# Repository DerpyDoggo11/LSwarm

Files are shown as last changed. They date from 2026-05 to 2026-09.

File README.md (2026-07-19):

# LSwarm Mk.1
Micro-drone swarm as a light display

## 3D Preview
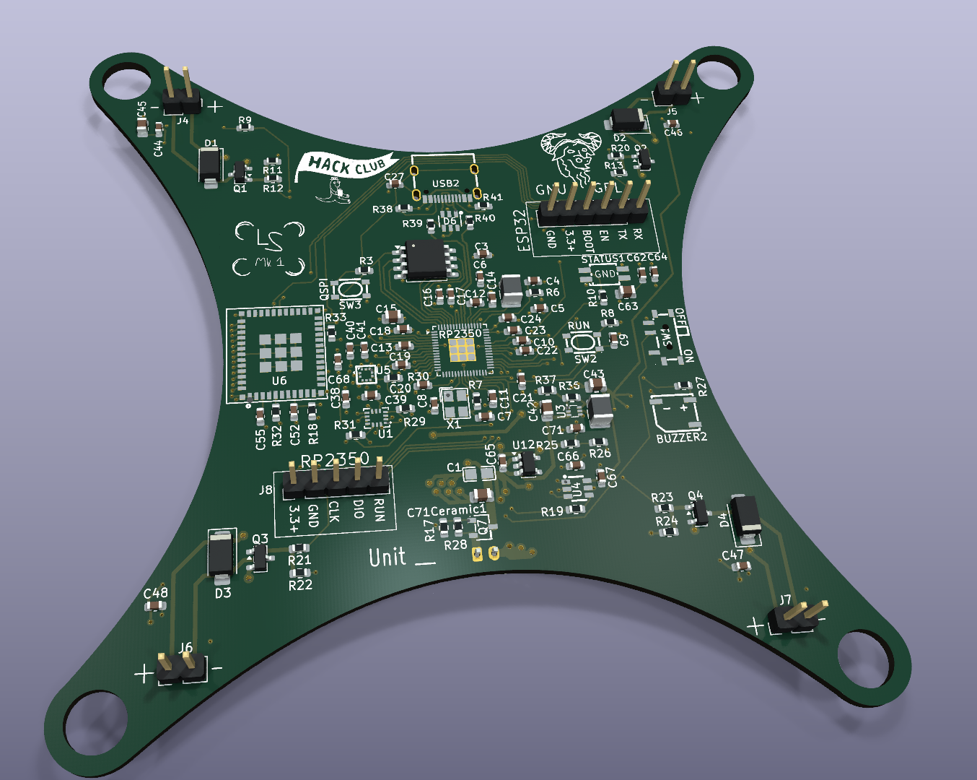
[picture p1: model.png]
3D PCB


## Wiring
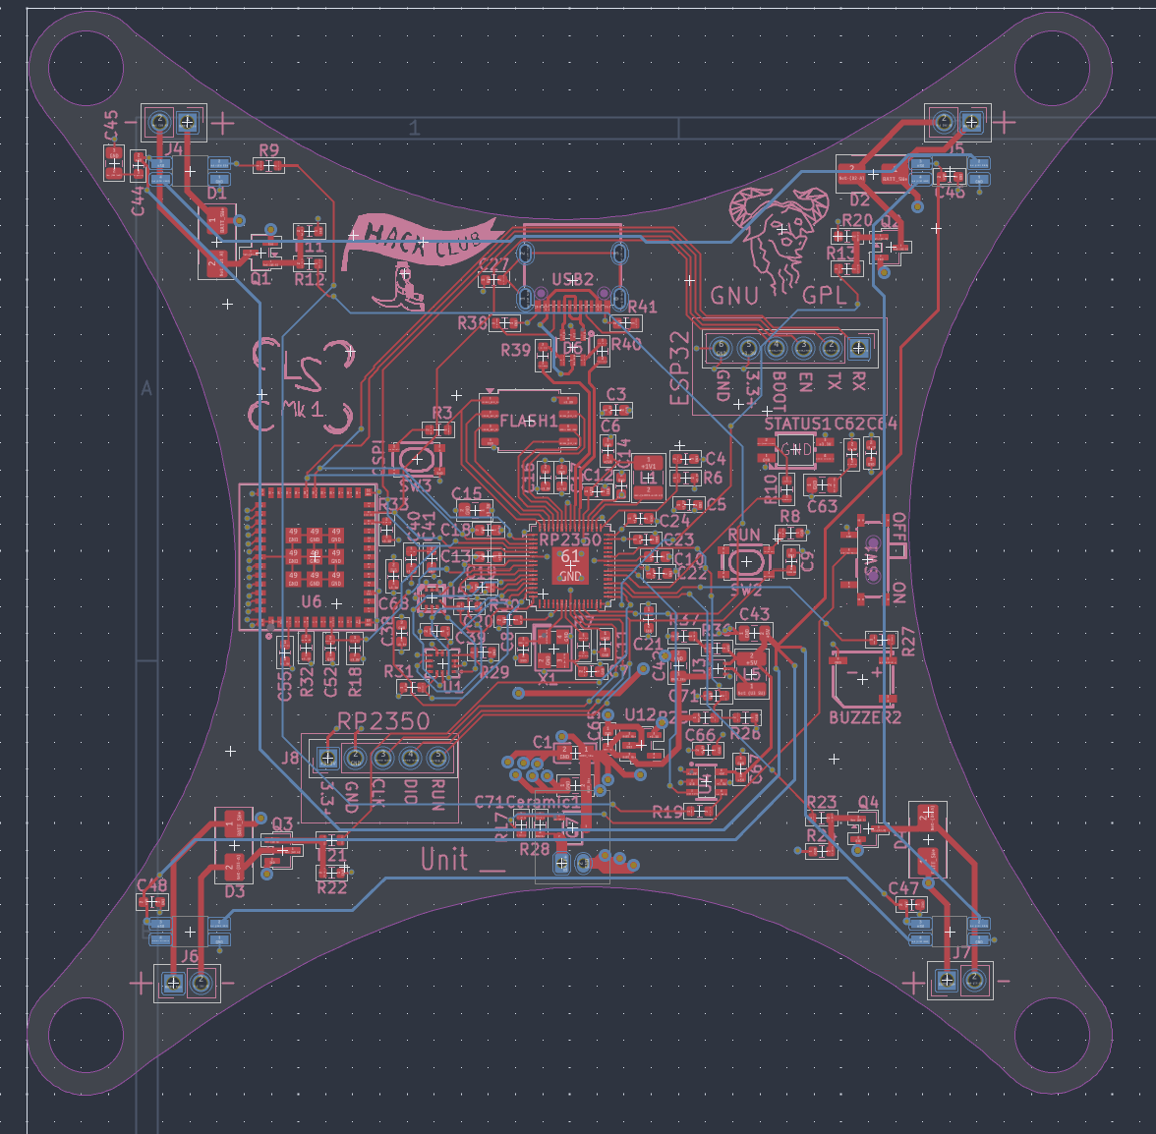
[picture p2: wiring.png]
PCB


## Schematic
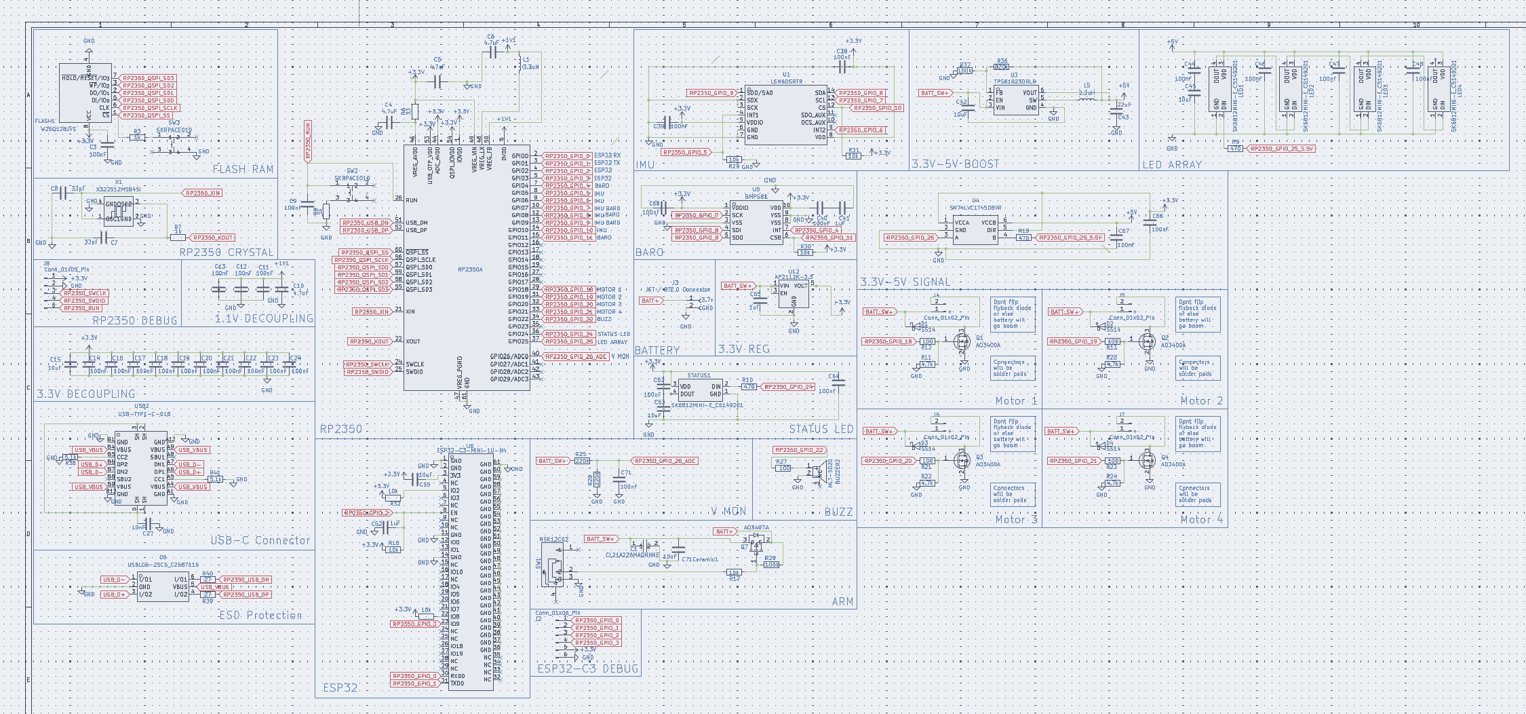
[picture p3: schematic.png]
Schematic


### Download ./latestProduction to begin fabricating the PCB

## Introduction
The LSwarm Mk.1 is a cheap open-source microdrone platform for making drone swarms. Instead of GPS, it uses UWB frequencies to communicate with ground anchors (see [LS Anchor](https://github.com/DerpyDoggo11/LSwarm-Anchor)) for positioning. To fabricate these drones yourself, see the bill of materials below and follow the instructions. 

Also, its all open sourced under the GNU GPL license! (do what you will with the code and designs but make sure to keep it open-source! :D)

### Are drone swarms legal in the US?
TLDR: yes and no, mostly no but sometimes yes. 

In the US, flying more than one drone by yourself outside is technically not legal without a permit, but flying indoors (or under some netting outside) is perfectly allowed, so make sure you understand this before buying or assembling any components.

If you live outside of the US, your restrictions will be different so make sure to check with your local government. 

## Bill of Materials 

### (Minimum build for testing: 5 drones)

| Quantity | Components | Price | Link |
|--- |---|---| -----|
| 20  | Brushed DC Motors | ~$9.68 | [here](https://www.aliexpress.us/item/3256810271706869.html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)
| 5  | 1s 450mAh BT2.0 Batteries | ~$11.21 | [here](https://www.aliexpress.us/item/3256810349502140.html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)
| 1 | 1s BT2.0 Charger | ~18.18 | [here](https://www.aliexpress.us/item/3256811772590472.html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) 
|5 | 2.4G Wifi Antenna | ~$3.52 | [here](https://www.aliexpress.us/item/3256802833801038.html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)
| 5 | BMP581 (hand solder) | ~$20.34 | [here](https://www.lcsc.com/product-detail/C5362283.html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)
| 5 | LSM6DSRTR (hand solder) | ~$17.33 | [here](https://www.lcsc.com/product-detail/C784817.html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)
| 5  | Mk.1 PCBs | ~$125 (with shipping, cost can vary widely however) | Download repo, extract fabrication files, and fabricate through JLCPCB (complete instructions for this may come soon)

Total cost: **$218.49**

Cost per drone: **$41.76**

----

### (Ideal build for full display: 20 drones)

| Quantity | Components | Price | Link |
|--- |---|---| -----|
| 80  | Brushed DC Motors | ~$54.88  | [here](https://www.aliexpress.us/item/3256810271706869.html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)
| 20  | 1s 450mAh BT2.0 Batteries | ~$61.82  | [here](https://www.aliexpress.us/item/3256810349502140.html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)
| 2 | 1s BT2.0 Charger | ~$36.36 | [here](https://www.aliexpress.us/item/3256811772590472.html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) 
| 20 | 2.4G Wifi Antenna | ~$14.08 | [here](https://www.aliexpress.us/item/3256802833801038.html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)
| 20 | BMP581 (hand solder) | ~$74.76 | [here](https://www.lcsc.com/product-detail/C5362283.html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)
| 20 | LSM6DSRTR (hand solder) | ~$60.13 | [here](https://www.lcsc.com/product-detail/C784817.html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)
| 20  | Mk.1 PCBs | ~$200 (with shipping, cost can vary widely however) | Download repo, extract fabrication files, and fabricate through JLCPCB (complete instructions for this may come soon)

Total cost: **$562.95**

Cost per drone: **$25.40**

----

## Tools / Other parts:
- Raspberry PI Zero 2 W or equivalent (or just a computer/laptop)
- UWB Anchors ([LS Anchor](https://github.com/DerpyDoggo11/LSwarm-Anchor) or equivalent UWB module (must have wifi)) 
- Hot-air reflow station or SMD hot plate
- Solder paste for SMD components
- Tweezers for SMD components
- Soldering iron + solder
- Wire strippers/cutters
- Zipties, tape, or velcro straps
- Hot glue + hot glue gun

## Assembly
1. Apply solder paste onto the smd joints for the BMP581 and LSM6DSRTR.
2. Carefully align the components and place using tweezers
3. Use a hot-air gun (preferred over smd hot plate to not mess up any other components) on high heat to quickly heat up the solder paste (prolonged heat may damage components)
4. Fit motors into mounting holes (make sure they are aligned properly on all sides) use wire strippers to cut and solder on motor wires. Apply hot glue or equivalent to the motors to keep them in place.
5. Use wire strippers to cut and solder on battery connector wires to PCB.
6. Attach battery with velcro, zipties, or tape.
7. Plug in battery and flash software with the USB-C port.

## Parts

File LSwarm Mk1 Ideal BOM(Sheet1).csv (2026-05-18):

Quantity | Component | Price | Link
80 | Brushed DC Motor | $54.88 | https://www.aliexpress.us/item/3256810271706869.html
20 | 1s 450mAh BT2.0 Battery | $61.82 | https://www.aliexpress.us/item/3256810349502140.html?curPageLogUid=6cUgOJiOwfNW
2 | 1s BT2.0 Charger | $36.36 | https://www.aliexpress.us/item/3256811772590472.html?curPageLogUid=pie8lE5eVKgd
20 | BMP581 (hand solder) | $74.76 | https://www.lcsc.com/product-detail/C5362283.html?s_z=s_p_BMP581
20 | LSM6DSRTR (hand solder) | $60.13 | https://www.lcsc.com/product-detail/C784817.html?s_z=s_q_LSM6DSR
20 | BT2.0 Battery Connector | $61 | https://www.aliexpress.us/item/3256809239979303.html?curPageLogUid=TSeGJiqu7rZ1 | Note: select "1S Whoop"
20 | 2.4G Wifi Antenna | $14.08 | https://www.aliexpress.us/item/3256802833801038.html?curPageLogUid=rLnZuf4b98Bi
20 | Custom PCB | $200 | Fab files available on github
Total: | $562.95
Unit Cost: | $25.40

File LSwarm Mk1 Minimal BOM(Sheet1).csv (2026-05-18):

Quantity | Component | Price | Link
20 | Brushed DC Motor | $9.68 | https://www.aliexpress.us/item/3256810271706869.html
5 | 1s 450mAh BT2.0 Battery | $11.21 | https://www.aliexpress.us/item/3256810349502140.html?curPageLogUid=6cUgOJiOwfNW
1 | 1s BT2.0 Charger | $18.18 | https://www.aliexpress.us/item/3256811772590472.html?curPageLogUid=pie8lE5eVKgd
5 | BMP581 (hand solder) | $20.34 | https://www.lcsc.com/product-detail/C5362283.html?s_z=s_p_BMP581
5 | LSM6DSRTR (hand solder) | $17.33 | https://www.lcsc.com/product-detail/C784817.html?s_z=s_q_LSM6DSR
5 | BT2.0 Battery Connector | $13 | https://www.aliexpress.us/item/3256809239979303.html?curPageLogUid=TSeGJiqu7rZ1 | Note: select "1S Whoop"
5 | 2.4G Wifi Antenna | $3.52 | https://www.aliexpress.us/item/3256802833801038.html?curPageLogUid=rLnZuf4b98Bi
5 | Custom PCB | $125 | Fab files available on github
Total: | $218.49
Unit Cost: | $41.76

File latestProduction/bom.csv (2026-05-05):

Designator | Footprint | Quantity | Value | LCSC Part #
BUZZER2 | BUZ-SMD_L5.0-W5.5-P4.60 | 1 | MLT-5020 | C94598
C1 | C0805 | 1 | CL21A226MAQNNNE | C45783
C10, C4, C5, C6 | 0603 | 4 | 4.7uF
C11, C12, C13, C14, C16, C17, C18, C19, C20, C21, C22, C23, C24, C3, C38, C39, C40, C44, C46, C47, C48, C49, C50, C51, C53, C56, C57, C58, C62, C64, C66, C67, C68, C71, C9 | 0603 | 35 | 100nF
C15, C42, C45, C63, C71CERAMIC1 | 0805 | 5 | 10uF
C26, C54 | 0603 | 2 | 10nF
C41, C59, C65 | 0603 | 3 | 1uF
C43 | 0805 | 1 | 22uF
C60, C61 | 0603 | 2 | 3.3pF
C7, C8 | 0603 | 2 | 15pF
D1, D2, D3, D4 | D_SMA | 4 | SS14
ESP32 | QFN-32-1EP_5x5mm_P0.5mm_EP3.7x3.7mm | 1 | ESP32-C3
FLASH1 | SOIC-8_5.3x5.3mm_P1.27mm | 1 | W25Q128JVS
JP1 | RF-SMD_FRF05002-JSS103M | 1 | U.FL-R-SMT-1 | C88374
L1 | 1210 | 1 | 3.3uH
L5 | 1210 | 1 | 2.2uH
L7 | 0402 | 1 | 2nH
L8 | 0402 | 1 | 2.2nH
Q1, Q2, Q3, Q4 | SOT-23 | 4 | AO3400A
Q7 | SOT-23-3_L2.9-W1.6-P1.90-LS2.8-BR | 1 | AO3407A | C15155
R10, R19, R9 | 0603 | 3 | 470
R11, R20, R22, R24 | 0603 | 4 | 4.7k
R12, R13, R21, R23, R27 | 0603 | 5 | 100
R14, R15, R16, R17, R29, R30, R31 | 0603 | 7 | 10k
R25, R26 | 0603 | 2 | 220k
R28, R37 | 0603 | 2 | 100k
R3, R7, R8 | 0603 | 3 | 1k
R32, R33 | 0603 | 2 | 5.1k
R34, R35 | 0603 | 2 | 27
R36 | 0603 | 1 | 820k
R6 | 0603 | 1 | 33
RP2350 | QFN-60-1EP_7x7mm_P0.4mm_EP3.4x3.4mm | 1 | RP2350A
STATUS1 | LED-SMD_4P-L3.2-W2.8-LS5.9_SK6812MINI-E | 1 | SK6812MINI-E_C5149201 | C5149201
SW1 | SW-TH_MSK12C02 | 1 | MSK12C02 | C431540
SW2, SW3, SW4, SW5 | KEY-SMD_4P-L4.2-W3.2-P2.20-LS4.6 | 4 | SKRPACE010 | C139797
U1 | LGA-14_L3.0-W2.5-P0.50-BR | 1 | LSM6DSRTR | C784817
U12 | SOT-23-5 | 1 | AP2112K-3.3
U3 | SOT-563_L1.6-W1.2-P0.50-LS1.6-BR | 1 | TPS61023DRLR | C919459
U4 | SOT-23-6_L2.9-W1.6-P0.95-LS2.8-BR | 1 | SN74LVC1T45DBVR | C7843
U5 | LGA-10_L2.0-W2.0-P0.50-TL_BMP581 | 1 | BMP581 | C5362283
USB1 | USB-C_SMD-TYPE-C-31-M-12 | 1 | USB-TYPE-C-018 | C2927038
X1 | CRYSTAL-SMD_4P-L3.2-W2.5-BL | 1 | X322512MSB4SI | C9002

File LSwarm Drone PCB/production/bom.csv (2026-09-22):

Designator | Footprint | Quantity | Value | LCSC Part #
BUZZER2 | BUZ-SMD_L5.0-W5.5-P4.60 | 1 | MLT-5020 | C94598
C1 | C0805 | 1 | CL21A226MAQNNNE | C45783
C10, C4, C5, C6 | 0603 | 4 | 4.7uF
C11, C12, C13, C14, C16, C17, C18, C19, C20, C21, C22, C23, C24, C3, C38, C39, C40, C44, C46, C47, C48, C56, C58, C59, C61, C62, C64, C66, C67, C68, C71, C9 | 0603 | 32 | 100nF
C15, C42, C45, C63, C71CERAMIC1 | 0805 | 5 | 10uF
C27 | 0603 | 1 | 10nF
C41, C52, C65 | 0603 | 3 | 1uF
C43 | 0805 | 1 | 22uF
C55, C69 | 0603 | 2 | 10uF
C7, C8 | 0603 | 2 | 33pF
D1, D2, D3, D4 | D_SMA | 4 | SS14
D6 | SOT-23-6_L2.9-W1.6-P0.95-LS2.8-BL | 1 | USBLC6-2SC6_C2687116 | C2687116
FLASH1 | SOIC-8_5.3x5.3mm_P1.27mm | 1 | W25Q128JVS
L1 | 1210 | 1 | 3.3uH
L2 | L0805 | 1 | MPZ2012S601AT000 | C21519
L5 | 1210 | 1 | 2.2uH
LED1, LED2, LED3, LED4, STATUS1 | LED-SMD_4P-L3.2-W2.8-LS5.9_SK6812MINI-E | 5 | SK6812MINI-E_C5149201 | C5149201
Q1, Q2, Q3, Q4 | SOT-23 | 4 | AO3400A
Q7 | SOT-23-3_L2.9-W1.6-P1.90-LS2.8-BR | 1 | AO3407A | C15155
R10, R19, R9 | 0603 | 3 | 470ohm
R11, R20, R22, R24 | 0603 | 4 | 4.7kohm
R12, R13, R21, R23, R27 | 0603 | 5 | 100ohm
R14, R15, R28, R37, R43 | 0603 | 5 | 100kohm
R17, R18, R29, R30, R31, R32, R33, R42 | 0603 | 8 | 10kohm
R25, R26 | 0603 | 2 | 220kohm
R3, R7, R8 | 0603 | 3 | 1kohm
R36 | 0603 | 1 | 820kohm
R38, R41 | 0603 | 2 | 5.1kohm
R39, R40 | 0603 | 2 | 27ohm
R6 | 0603 | 1 | 33ohm
RP2350 | QFN-60-1EP_7x7mm_P0.4mm_EP3.4x3.4mm | 1 | RP2350A
SW1 | SW-TH_MSK12C02 | 1 | MSK12C02 | C431540
SW2, SW3 | KEY-SMD_4P-L4.2-W3.2-P2.20-LS4.6 | 2 | SKRPACE010 | C139797
TP34 | TestPoint_Pad_1.0x1.0mm | 1 | ESP32_EN
TP35 | TestPoint_Pad_1.0x1.0mm | 1 | RP2350_RUN
TP36 | TestPoint_Pad_1.0x1.0mm | 1 | ESP32_BOOT
TP37 | TestPoint_Pad_1.0x1.0mm | 1 | RP2350_SWDIO
TP38 | TestPoint_Pad_1.0x1.0mm | 1 | ESP32_RX
TP39 | TestPoint_Pad_1.0x1.0mm | 1 | RP2350_SWCLK
TP40 | TestPoint_Pad_1.0x1.0mm | 1 | ESP32_TX
TP41 | TestPoint_Pad_1.0x1.0mm | 1 | ESP32_+3.3v
TP42 | TestPoint_Pad_1.0x1.0mm | 1 | ESP32_GND
TP43 | TestPoint_Pad_1.0x1.0mm | 1 | RP2350_GND
TP44 | TestPoint_Pad_1.0x1.0mm | 1 | RP2350_+3.3V
U1 | LGA-14_L3.0-W2.5-P0.50-BR | 1 | LSM6DSRTR | C784817
U12 | SOT-23-5 | 1 | AP2112K-3.3
U2 | WIRELM-SMD_BU03 | 1 | BU03 | C42419011
U3 | SOT-563_L1.6-W1.2-P0.50-LS1.6-BR | 1 | TPS61023DRLR | C919459
U4 | SOT-23-6_L2.9-W1.6-P0.95-LS2.8-BR | 1 | SN74LVC1T45DBVR | C7843
U5 | LGA-10_L2.0-W2.0-P0.50-TL_BMP581 | 1 | BMP581 | C5362283
U6 | WIFIM-SMD_61P-L13.2-W12.5-P0.80 | 1 | ESP32-C3-MINI-1U-N4 | C2911374
USB2 | USB-C_SMD-TYPE-C-31-M-12 | 1 | USB-TYPE-C-018 | C2927038
X1 | CRYSTAL-SMD_4P-L3.2-W2.5-BL | 1 | X322512MSB4SI | C9002

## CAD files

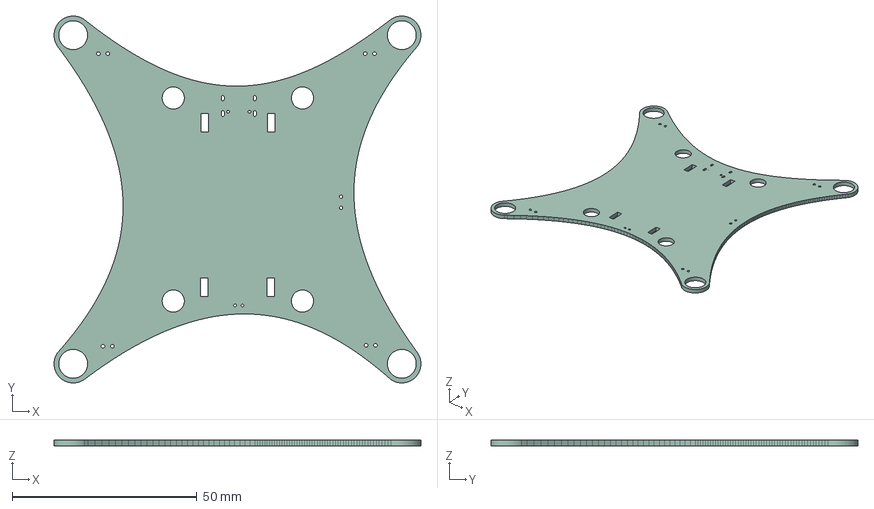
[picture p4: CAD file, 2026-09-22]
LSwarm Drone PCB/LSwarm Mk1.step
99.4 x 99.4 x 1.51 mm

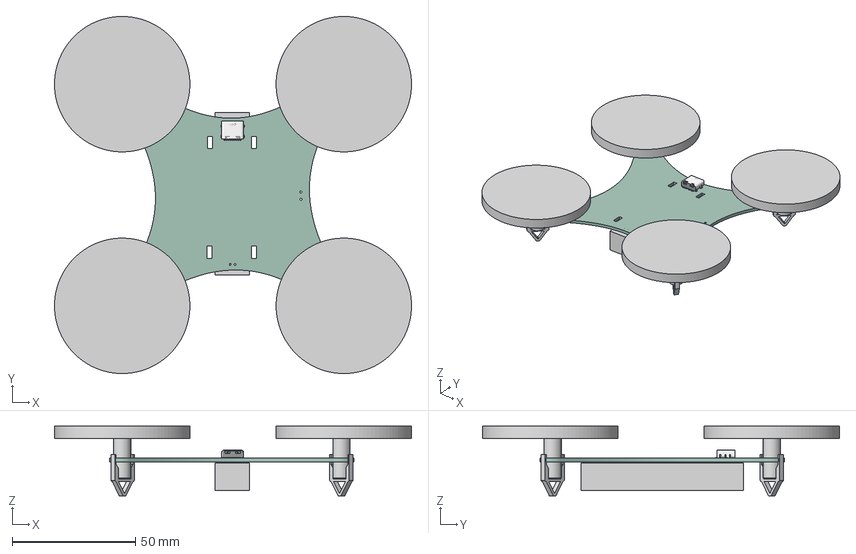
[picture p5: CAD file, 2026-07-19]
LSwarm Drone PCB/Drone.3mf
145.0 x 145.0 x 28.2 mm

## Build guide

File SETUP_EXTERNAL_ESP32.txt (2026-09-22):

===========================================================================
 LSwarm - Wiring an external ESP32-S3 Super Mini to the drone and the anchor
===========================================================================

WHY: The on-board ESP32-C3 chips (drone U8, anchor U6) don't work. This guide
bypasses them with an external ESP32-S3 Super Mini on each board, and adds the
Raspberry Pi Zero 2 W ground station.

Read the "IMPORTANT REALITY CHECK" section first - it changes what you buy.

---------------------------------------------------------------------------
 IMPORTANT REALITY CHECK (read this)
---------------------------------------------------------------------------
1. The ANCHOR has a UWB radio on the PCB (module U2, "BU03" / DW3000 by the
   antenna). External S3 drives it -> responder.

2. The DRONE has a UWB tag on the PCB too. Its DW3000 nets route to the dead
   ESP32-C3 pads (WAKEUP=C3 IO1, IRQ=IO3, MISO=IO4, MOSI=IO5, CLK=IO6, CS=IO7,
   RST=IO10). The external S3 taps those pads and drives the tag -> the drone
   ranges the anchors and gets a real position. Wiring in section D2.
   Build the drone ESP firmware with USE_UWB=1 (default).

3. WiFi + ESP-NOW share one radio. Both must sit on the Pi AP's channel. The
   firmware forces this (esp_wifi_set_channel to WiFi.channel()). Don't fight
   it - just let all drones join the Pi AP.

---------------------------------------------------------------------------
 PARTS
---------------------------------------------------------------------------
- 1x ESP32-S3 Super Mini per drone
- 1x ESP32-S3 Super Mini per anchor
  (UWB radios are already on both PCBs - no extra UWB modules to buy)
- Raspberry Pi Zero 2 W + SD card
- Thin silicone wire (30 AWG), soldering iron

===========================================================================
 A) ESP32-S3 SUPER MINI PIN USAGE (both boards, one BOM)
===========================================================================
Avoid these S3 pins: 0,3,45,46 (strapping), 19,20 (USB D-/D+),
43,44 (USB-serial TX/RX), 48 (on-board RGB LED - firmware uses it for status).

Function            S3 GPIO
------------------  -------
UART link RX          4     (drone only)
UART link TX          5     (drone only)
DW3000 MOSI          11
DW3000 SCK           12
DW3000 MISO          13
DW3000 CS            10
DW3000 IRQ            9
DW3000 RST            8
DW3000 WAKEUP         7
Anchor VMON (ADC)     1     (anchor only)
Status LED           48     (on-board RGB, no wire)

===========================================================================
 D) DRONE WIRING
===========================================================================

D1) RP2350 <-> S3 link  (the 6-pin "ESP32" header on the drone PCB)
    The header is silkscreened:  GND  3V3  BOOT  EN  TX  RX

    Header pin   ->  ESP32-S3 Super Mini
    ----------       -------------------
    GND          ->  GND
    3V3          ->  3V3        (see power note below)
    TX           ->  GPIO4  (S3 RX)    <-- cross-over: board TX to S3 RX
    RX           ->  GPIO5  (S3 TX)    <-- cross-over: board RX to S3 TX
    BOOT         ->  (leave open)
    EN           ->  (leave open)

    - Cross the TX/RX. Header TX is the RP2350's output (GPIO0); it must land
      on the S3's RX. Header RX is the RP2350's input (GPIO1); it takes the
      S3's TX.
    - BOOT/EN were only used to auto-flash the dead C3. You flash the S3 over
      its own USB-C now, so leave them open. The RP2350 firmware (built with
      -DEXTERNAL_ESP) also holds the C3 in reset so it can't jam the bus.
    - POWER: the header 3V3 comes from the drone's AP2112K-3.3 (600 mA). WiFi
      TX peaks can brown that out. Safer: power the S3 from its own USB during
      bench work, or run a wire from the board's 5V (boost output) to the S3
      "5V" pin and leave header 3V3 disconnected. Always tie GND either way.

D2) DRONE UWB TAG  (on-board DW3000 - tap at the dead C3 pads)
    The tag's DW nets land on the C3-MINI (U8) pads. Tap each and run to the S3
    SPI pins. Find the pad by the C3 GPIO it used:

      DW net    C3 pad (U8)   ->  ESP32-S3 GPIO
      -------   -----------       -------------
      MOSI      IO5           ->  11
      CLK/SCK   IO6           ->  12
      MISO      IO4           ->  13
      CS        IO7           ->  10
      IRQ       IO3           ->   9
      RST       IO10          ->   8
      WAKEUP    IO1           ->   7

    - Lift or disable the C3 (U8) so it can't fight the SPI (the RP2350 already
      holds it in reset via -DEXTERNAL_ESP, but a powered C3 can still drive
      IO pins - safest to not populate it or cut its EN).
    - Power the DW rail from the board 3.3 V; share GND with the S3.

===========================================================================
 E) ANCHOR WIRING
===========================================================================
The anchor's DW3000 (U2) is already on the PCB; its SPI nets used to run to
the dead C3 (U6). Tap those nets and run them to the external S3. Easiest tap
points are the C3-MINI pads (U6) or the U2 module pins. Net names are on the
anchor schematic (right-hand "UWB ANCHOR" block).

    DW3000 net (schematic)   ->  ESP32-S3 GPIO
    ----------------------       -------------
    DW_MOSI                  ->  11
    DW_CLK  (SCK)            ->  12
    DW_MISO                  ->  13
    DW_Sn   (CS)             ->  10
    DW_IRQ                   ->   9
    DW_RST                  ->    8
    DW_WAKEUP               ->    7
    UW_3.3V  (module 3V3)   ->   S3 3V3
    GND                     ->   S3 GND
    ESP32_VMON_ADC (test pt)->   S3 GPIO1   (optional battery monitor)

    - Do NOT populate / leave dead the C3 (U6). If it's already soldered, lift
      it or cut its EN so it can't drive the SPI lines against the S3.
    - Power the S3 from the anchor's 3.3 V rail (UW_3.3V / board 3V3) and share
      GND. The anchor LDO (AP2112K) can feed the S3.

===========================================================================
 F) FIRMWARE - what changed and how to build
===========================================================================
All three firmwares are in the repos. PlatformIO (VS Code) recommended.

F1) Drone RP2350   (LSwarm/RP2350 Firmware)
    - Build/flash the "drone" env (now built with -DEXTERNAL_ESP). Flash over
      the RP2350 USB-C as before.
    - New behaviour: sends "T,vbat,armed,usb" telemetry to the S3 every 200 ms,
      accepts "P,x,y,z,q" position and "C,verb,args" commands from the S3
      (Pi commands are forwarded through). Console commands are unchanged.

F2) Drone ESP32-S3   (LSwarm/ESP32 Firmware)
    - EDIT the config block at the top of src/main.cpp:
        DRONE_ID, WIFI_SSID, WIFI_PASS, PI_IP, ANCHORS[] list.
    - env "drone_s3". Flash over the S3 USB-C.
    - Keep -DUSE_UWB=1 (default): the drone has an on-board UWB tag (D2).
    - Uses the Makerfabs DW3000 Arduino library (pulled by lib_deps).

F3) Anchor ESP32-S3   (LSwarm Anchor/ESP32 Firmware)
    - EDIT the config block in src/main.cpp: ANCHOR_ID (unique per anchor!),
      WIFI_SSID, WIFI_PASS, PI_IP.
    - env "anchor_s3". Flash over the S3 USB-C.

F4) CALIBRATION (the one physical knob)
    Both uwb.h files have ANTENNA_DELAY = 16385. Put a tag ~5.00 m from an
    anchor, read the ranges the drone reports, and nudge ANTENNA_DELAY until
    the number matches the tape measure. Same value on tag and anchors.

===========================================================================
 G) RASPBERRY PI ZERO 2 W GROUND STATION
===========================================================================
Files: LSwarm/Pi Ground Station/ (ground_station.py, anchors.json)

G1) Make the Pi a WiFi access point named "LSwarm" (must match the firmware
    WIFI_SSID/WIFI_PASS). On Raspberry Pi OS Bookworm (NetworkManager):

      sudo nmcli device wifi hotspot ssid LSwarm password swarmnet ifname wlan0
      sudo nmcli connection modify Hotspot ipv4.addresses 192.168.4.1/24
      sudo nmcli connection modify Hotspot connection.autoconnect yes
      sudo nmcli connection up Hotspot

    The AP is now 192.168.4.1 - that's the PI_IP in the firmware. Drones and
    anchors will DHCP onto 192.168.4.x.

G2) Run the ground station (also serves the web apps):
      sudo apt install python3-numpy
      cd "Pi Ground Station"
      python3 ground_station.py --demo   # sanity-check the math (optional)
      python3 ground_station.py          # UDP solver + web dashboard

    One process does it all: UDP solving on :9000, web UI on :8080.

G3) SET UP ANCHORS ON THE MAP (no more hand-edited coordinates):
    From any device on the LSwarm AP open:
      http://192.168.4.1:8080/setup
    - The map is live satellite imagery (Esri). Pan to your site.
    - Click to drop each anchor; drag to fine-tune; set its z (height) and give
      each anchor the SAME number as its firmware ANCHOR_ID.
    - Click "Set origin = map center" (this is local (0,0)), then "Save".
    - Saving writes config.json on the Pi. Imagery tiles you viewed are cached
      to Pi disk (tiles/), so the field works offline afterwards. Leaflet.js/css
      are already vendored locally - the web apps need NO internet at run time.

G4) LIVE DASHBOARD (auto-loads whatever setup saved):
      http://192.168.4.1:8080/
    - Anchors (yellow) and drones (blue/green) plotted on the same imagery,
      with trails. Coordinates shown both as local x/y/z metres and as lat/lon.
    - Tables: per-drone x,y,z,fix-quality,vbat,armed,uwb,age and per-anchor
      uwb/vbat/age. "link" dot is green while the SSE stream is live.
    - No upload step: the dashboard reads /config + /events from the same Pi,
      so a Save in /setup shows up here on the next refresh.

G5) TRY IT WITH NO HARDWARE (simulator):
      python3 ground_station.py        # terminal 1
      python3 sim.py 3                 # terminal 2 -> 3 virtual drones
    Open the dashboard and watch 3 drones circle the anchors. Confirms the
    whole pipe (ranges -> trilateration -> map) before you trust real radios.

G6) (optional) autostart: systemd service running `python3 ground_station.py`.

===========================================================================
 H) DATA FLOW SUMMARY
===========================================================================
  DW3000 tag (drone) --UWB TWR--> anchors                 -> ranges
  drone S3 --UDP "R,id,aid,dist,..."--> Pi                -> Pi trilaterates
  Pi --UDP "P,x,y,z,q"--> drone S3 --UART "P,..."--> RP2350
  drone S3 --ESP-NOW "N,id,x,y,z"--> peer drones          (formation spacing)
  RP2350 --UART "T,vbat,armed,usb"--> drone S3 --UDP "D,..."--> Pi
  anchor S3 --UDP "A,id,uwbok,vbat"--> Pi                 (health)
  Pi --UDP "C,verb,args"--> drone S3 --UART "C,..."--> RP2350   (choreography)

===========================================================================
 I) BRING-UP CHECKLIST
===========================================================================
[ ] Pi AP "LSwarm" up at 192.168.4.1
[ ] ground station running; dashboard opens at http://192.168.4.1:8080/
[ ] anchors placed + saved in /setup (numbers match firmware ANCHOR_IDs)
[ ] sim.py fleet shows drones moving on the map (pipe proven end-to-end)
[ ] each anchor: unique ANCHOR_ID, flashed, shows green LED, "A," seen on Pi
[ ] each drone RP2350: reflashed with EXTERNAL_ESP
[ ] each drone S3: config edited, flashed, "wifi ok" + "UWB ready" on console
[ ] drone reports "R," ranges to Pi; Pi replies "P,"; RP2350 sees position
[ ] ANTENNA_DELAY tuned against a tape measure
[ ] ESP-NOW: two drones see each other's "N," lines
===========================================================================

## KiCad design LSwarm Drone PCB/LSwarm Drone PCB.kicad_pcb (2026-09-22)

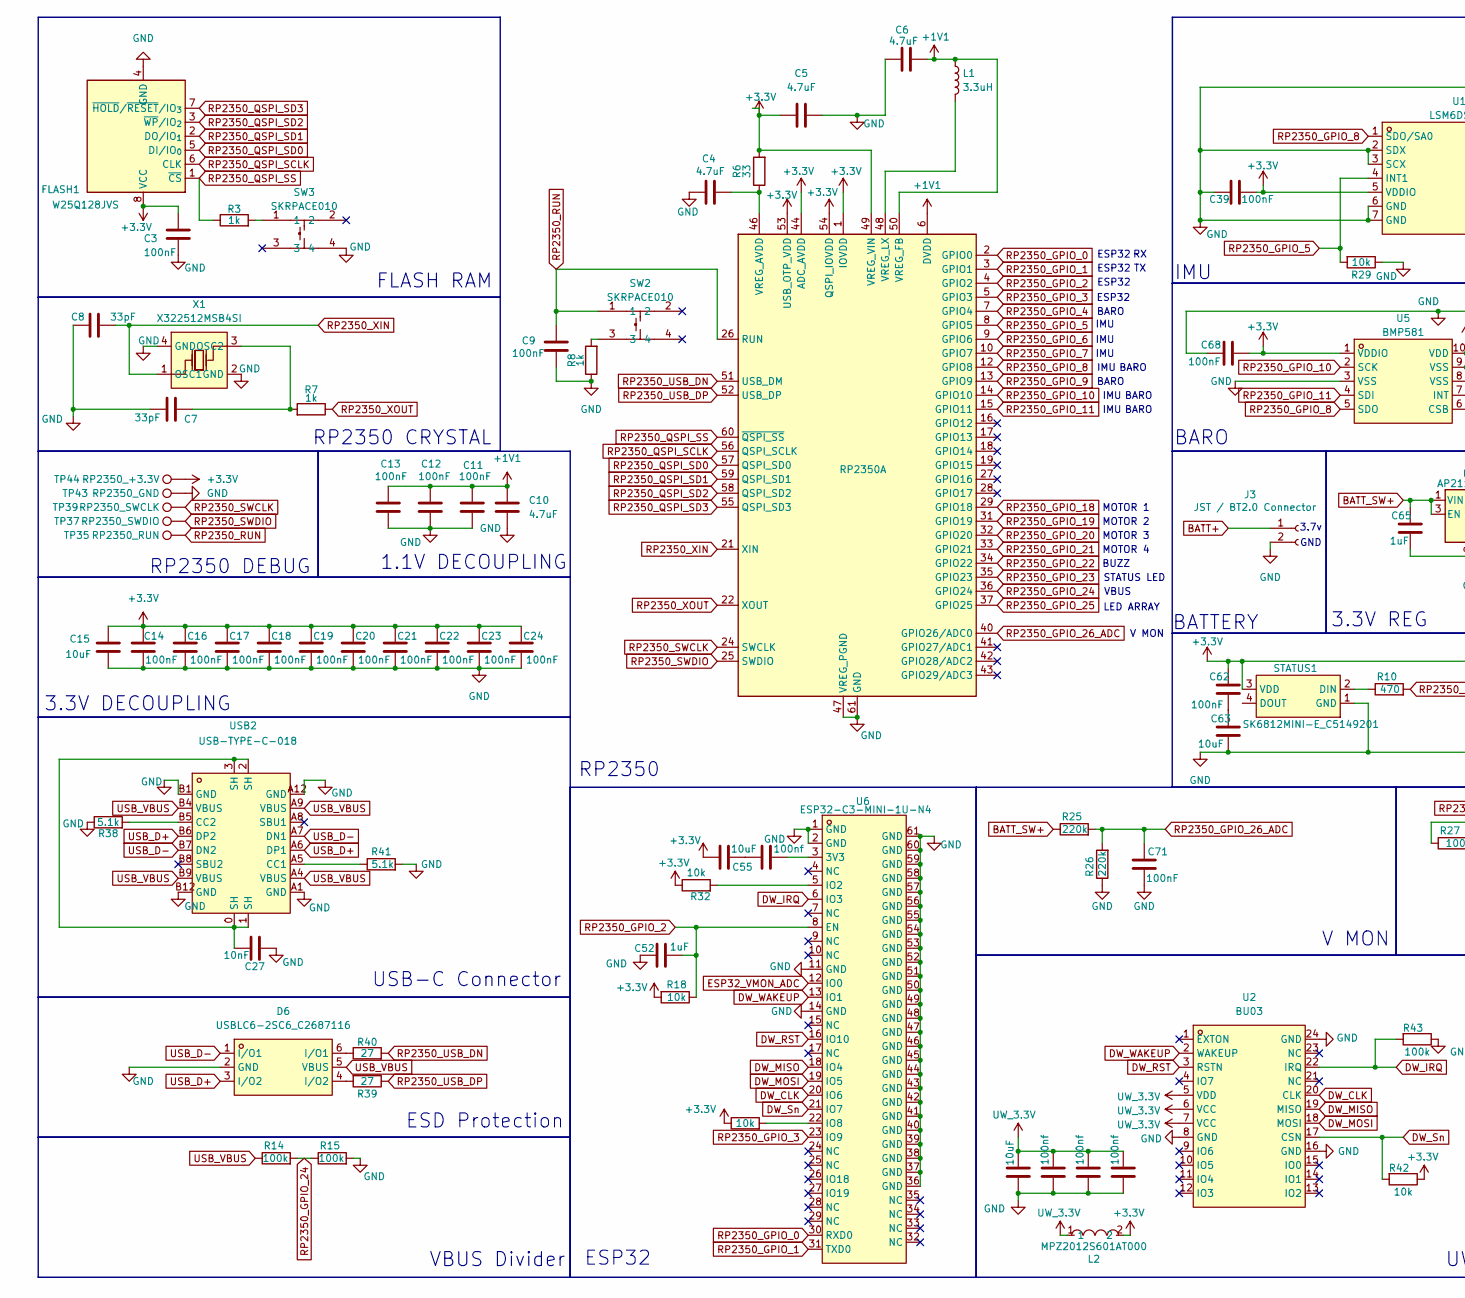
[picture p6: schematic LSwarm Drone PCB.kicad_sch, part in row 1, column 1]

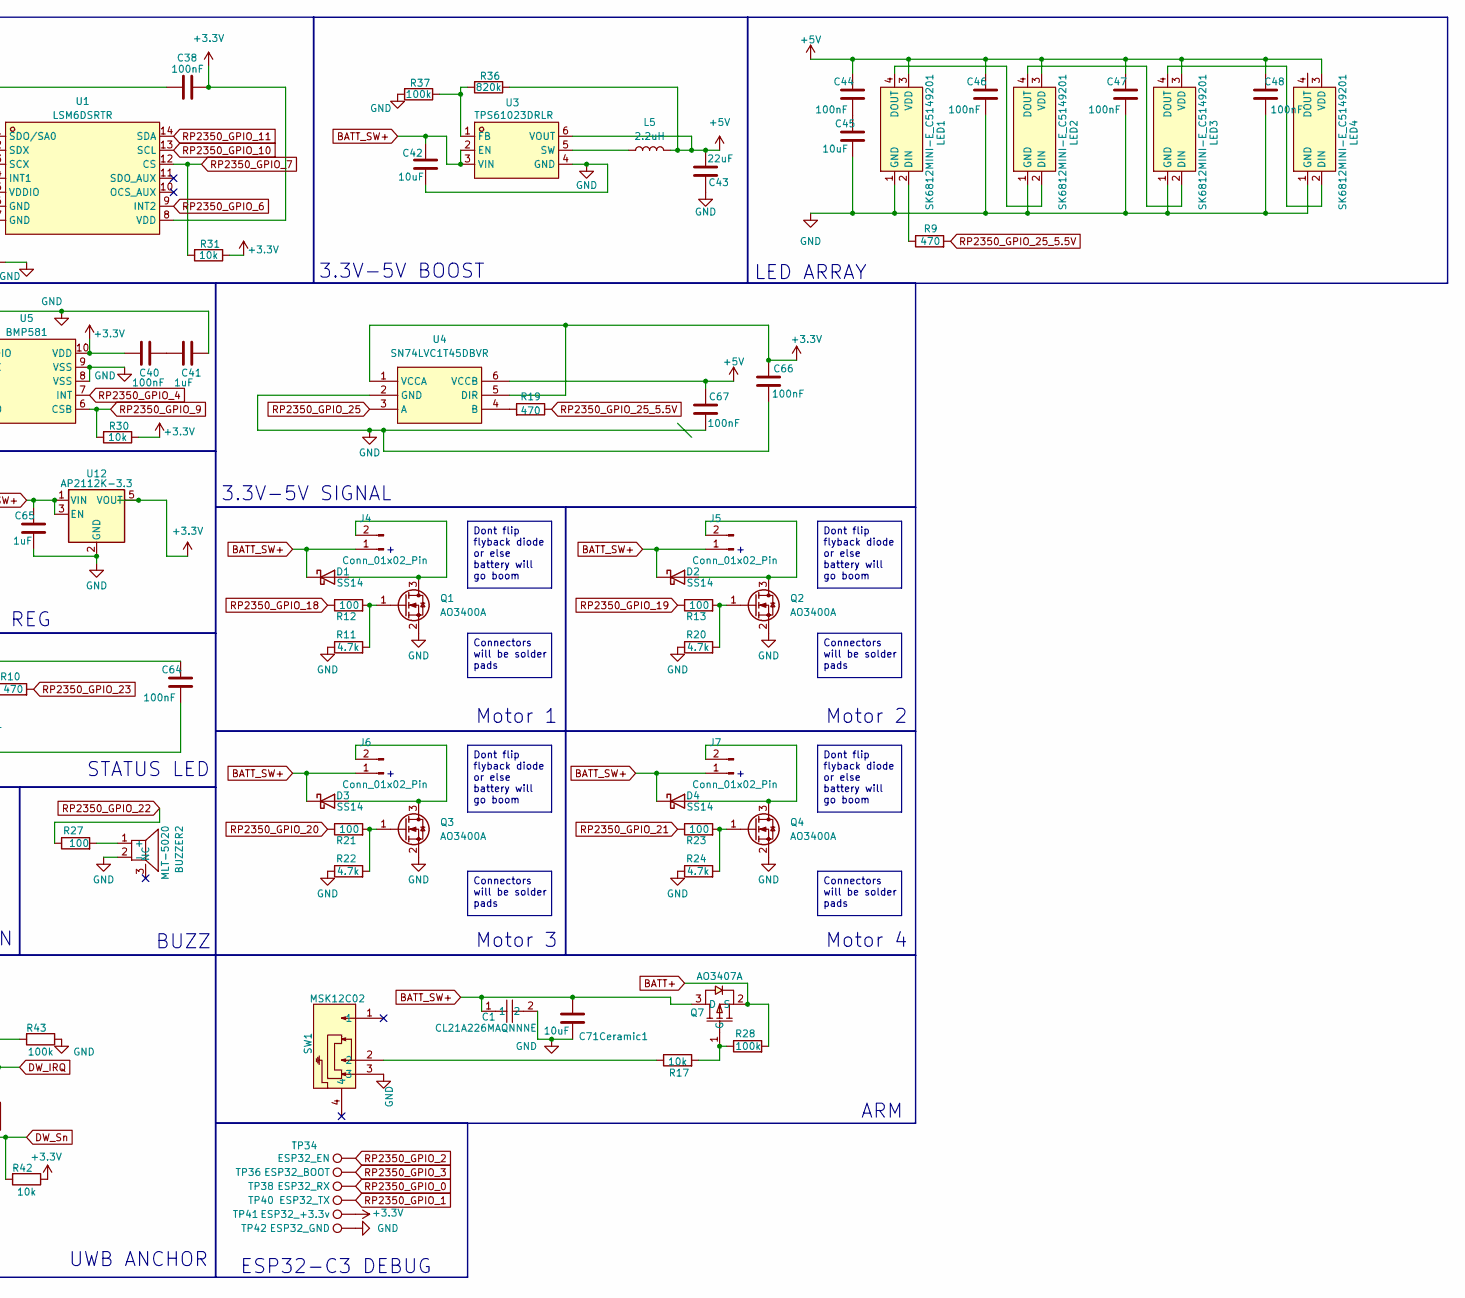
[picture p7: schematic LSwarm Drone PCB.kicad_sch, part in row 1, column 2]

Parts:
BUZZER2: MLT-5020; BUZ-SMD_L5.0-W5.5-P4.60; MPN MLT-5020; LCSC Part C94598
C1: CL21A226MAQNNNE; C0805; MPN CL21A226MAQNNNE; LCSC Part C45783
C3, C9, C11, C12, C13, C14, C16, C17, C18, C19, C20, C21, C22, C23, C24, C38, C39, C40, C44, C46, C47, C48, C62, C64, C66, C67, C68, C71: 100nF; C_0603_1608Metric
C4, C5, C6, C10: 4.7uF; C_0603_1608Metric
C7, C8: 33pF; C_0603_1608Metric
C15, C42, C45, C63, C71Ceramic1: 10uF; C_0805_2012Metric
C27: 10nF; C_0603_1608Metric
C41, C52, C65: 1uF; C_0603_1608Metric
C43: 22uF; C_0805_2012Metric
C55, C69: 10uF; C_0603_1608Metric
C56, C58, C59, C61: 100nf; C_0603_1608Metric
D1, D2, D3, D4: SS14; D_SMA
D6: USBLC6-2SC6_C2687116; SOT-23-6_L2.9-W1.6-P0.95-LS2.8-BL; MPN USBLC6-2SC6; LCSC Part C2687116
FLASH1: W25Q128JVS; SOIC-8_5.3x5.3mm_P1.27mm
J3: JST / BT2.0 Connector; JST_PH_S2B-PH-K_1x02_P2.00mm_Horizontal
J4, J5, J6, J7: Conn_01x02_Pin; PinHeader_1x02_P2.54mm_Vertical
L1: 3.3uH; L_1210_3225Metric
L2: MPZ2012S601AT000; L0805; MPN MPZ2012S601AT000; LCSC Part C21519
L5: 2.2uH; L_1210_3225Metric
LED1, LED2, LED3, LED4: SK6812MINI-E_C5149201; LED-SMD_4P-L3.2-W2.8-LS5.9_SK6812MINI-E; MPN SK6812MINI-E; LCSC Part C5149201
Q1, Q2, Q3, Q4: AO3400A; SOT-23
Q7: AO3407A; SOT-23-3_L2.9-W1.6-P1.90-LS2.8-BR; MPN AO3407A; LCSC Part C15155
R3, R7, R8: 1k; R_0603_1608Metric
R6: 33; R_0603_1608Metric
R9, R10, R19: 470; R_0603_1608Metric
R11, R20, R22, R24: 4.7k; R_0603_1608Metric
R12, R13, R21, R23, R27: 100; R_0603_1608Metric
R14, R15, R28, R37, R43: 100k; R_0603_1608Metric
R17, R18, R29, R30, R31, R32, R33, R42: 10k; R_0603_1608Metric
R25, R26: 220k; R_0603_1608Metric
R36: 820k; R_0603_1608Metric
R38, R41: 5.1k; R_0603_1608Metric
R39, R40: 27; R_0603_1608Metric
RP2350: RP2350A; QFN-60-1EP_7x7mm_P0.4mm_EP3.4x3.4mm
STATUS1: SK6812MINI-E_C5149201; LED-SMD_4P-L3.2-W2.8-LS5.9_SK6812MINI-E; MPN SK6812MINI-E; LCSC Part C5149201
SW1: MSK12C02; SW-TH_MSK12C02; MPN MSK12C02; LCSC Part C431540
SW2, SW3: SKRPACE010; KEY-SMD_4P-L4.2-W3.2-P2.20-LS4.6; MPN SKRPACE010; LCSC Part C139797
TP34: ESP32_EN; TestPoint_Pad_1.0x1.0mm
TP35: RP2350_RUN; TestPoint_Pad_1.0x1.0mm
TP36: ESP32_BOOT; TestPoint_Pad_1.0x1.0mm
TP37: RP2350_SWDIO; TestPoint_Pad_1.0x1.0mm
TP38: ESP32_RX; TestPoint_Pad_1.0x1.0mm
TP39: RP2350_SWCLK; TestPoint_Pad_1.0x1.0mm
TP40: ESP32_TX; TestPoint_Pad_1.0x1.0mm
TP41: ESP32_+3.3v; TestPoint_Pad_1.0x1.0mm
TP42: ESP32_GND; TestPoint_Pad_1.0x1.0mm
TP43: RP2350_GND; TestPoint_Pad_1.0x1.0mm
TP44: RP2350_+3.3V; TestPoint_Pad_1.0x1.0mm
U1: LSM6DSRTR; LGA-14_L3.0-W2.5-P0.50-BR; MPN LSM6DSRTR; LCSC Part C784817
U2: BU03; WIRELM-SMD_BU03; MPN BU03; LCSC Part C42419011
U3: TPS61023DRLR; SOT-563_L1.6-W1.2-P0.50-LS1.6-BR; MPN TPS61023DRLR; LCSC Part C919459
U4: SN74LVC1T45DBVR; SOT-23-6_L2.9-W1.6-P0.95-LS2.8-BR; MPN SN74LVC1T45DBVR; LCSC Part C7843
U5: BMP581; LGA-10_L2.0-W2.0-P0.50-TL_BMP581; MPN BMP581; LCSC Part C5362283
U6: ESP32-C3-MINI-1U-N4; WIFIM-SMD_61P-L13.2-W12.5-P0.80; MPN ESP32-C3-MINI-1U-N4; LCSC Part C2911374
U12: AP2112K-3.3; SOT-23-5
USB2: USB-TYPE-C-018; USB-C_SMD-TYPE-C-31-M-12; MPN USB-TYPE-C-018; LCSC Part C2927038
X1: X322512MSB4SI; CRYSTAL-SMD_4P-L3.2-W2.5-BL; MPN X322512MSB4SI; LCSC Part C9002

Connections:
+1V1: C6.2, C10.1, C11.1, C12.1, C13.1, L1.1, RP2350.6 (DVDD), RP2350.23 (DVDD), RP2350.39 (DVDD), RP2350.50 (VREG_FB)
+3.3V: C3.1, C5.1, C14.1, C15.1, C16.1, C17.1, C18.1, C19.1, C20.1, C21.1, C22.1, C23.1, C24.1, C38.1, C39.1, C40.2, C55.2, C62.2, C64.2, C66.2, C68.1, FLASH1.8 (VCC), L2.2, R6.2, R18.2, R30.1, R31.1, R32.1, R33.1, R42.1, RP2350.1 (IOVDD), RP2350.11 (IOVDD), RP2350.20 (IOVDD), RP2350.30 (IOVDD), RP2350.38 (IOVDD), RP2350.44 (ADC_AVDD), RP2350.45 (IOVDD), RP2350.49 (VREG_VIN), RP2350.53 (USB_OTP_VDD), RP2350.54 (QSPI_IOVDD), STATUS1.3 (VDD), TP41.1 (1_1), TP44.1 (1_1), U1.5 (VDDIO), U1.8 (VDD), U4.1 (VCCA), U4.5 (DIR), U5.1 (VDDIO), U5.10 (VDD), U12.5 (VOUT)
+5V: C43.2, C44.2, C46.2, C47.2, C48.2, C67.2, L5.2, LED1.3 (VDD), LED2.3 (VDD), LED3.3 (VDD), LED4.3 (VDD), R36.1, U3.6 (VOUT), U4.6 (VCCB)
BATT+: J3.1, Q7.2 (S), R28.2
BATT_SW+: C1.1, C42.1, C65.2, C71Ceramic1.2, D1.1 (K), D2.1 (K), D3.1 (K), D4.1 (K), J4.1, J5.1, J6.1, J7.1, Q7.3 (D), R25.1, U3.2 (EN), U3.3 (VIN), U12.1 (VIN), U12.3 (EN)
DW_CLK: U2.20 (CLK), U6.20 (IO6)
DW_IRQ: R43.2, U2.22 (IRQ), U6.6 (IO3)
DW_MISO: U2.19 (MISO), U6.18 (IO4)
DW_MOSI: U2.18 (MOSI), U6.19 (IO5)
DW_RST: U2.3 (RSTN), U6.16 (IO10)
DW_Sn: R42.2, U2.17 (CSN), U6.21 (IO7)
DW_WAKEUP: U2.2 (WAKEUP), U6.13 (IO1)
ESP32_VMON_ADC: U6.12 (IO0)
GND: BUZZER2.2 (-), C1.2, C3.2, C4.1, C5.2, C6.1, C7.1, C8.2, C9.2, C10.2, C11.2, C12.2, C13.2, C14.2, C15.2, C16.2, C17.2, C18.2, C19.2, C20.2, C21.2, C22.2, C23.2, C24.2, C27.1, C38.2, C39.2, C41.1, C42.2, C43.1, C45.1, C46.1, C47.1, C48.1, C52.1, C58.2, C59.2, C61.2, C63.1, C64.1, C65.1, C66.1, C67.1, C68.2, C69.2, C71.1, C71Ceramic1.1, D6.2 (GND), FLASH1.4 (GND), J3.2, LED1.1 (GND), LED2.1 (GND), LED3.1 (GND), LED4.1 (GND), Q1.2 (S), Q2.2 (S), Q3.2 (S), Q4.2 (S), R8.1, R11.1, R15.2, R20.1, R22.1, R24.1, R26.1, R29.1, R37.2, R38.1, R41.2, R43.1, RP2350.47 (VREG_PGND), RP2350.61 (GND), STATUS1.1 (GND), SW1.3, SW3.4, TP42.1 (1_1), TP43.1 (1_1), U1.2 (SDX), U1.3 (SCX), U1.6 (GND), U1.7 (GND), U2.8 (GND), U2.16 (GND), U2.24 (GND), U3.4 (GND), U4.2 (GND), U5.3 (VSS), U5.8 (VSS), U5.9 (VSS), U6.1 (GND), U6.2 (GND), U6.11 (GND), U6.14 (GND), U6.36 (GND), U6.37 (GND), U6.38 (GND), U6.39 (GND), U6.40 (GND), U6.41 (GND), U6.42 (GND), U6.43 (GND), U6.44 (GND), U6.45 (GND), U6.46 (GND), U6.47 (GND), U6.48 (GND), U6.49 (GND), U6.50 (GND), U6.51 (GND), U6.52 (GND), U6.53 (GND), U6.54 (GND), U6.55 (GND), U6.56 (GND), U6.57 (GND), U6.58 (GND), U6.59 (GND), U6.60 (GND), U6.61 (GND), U12.2 (GND), USB2.A1 (GND), USB2.A12 (GND), USB2.B1 (GND), USB2.B12 (GND), X1.2 (GND), X1.4 (GND)
unnamed: BUZZER2.1 (+), R27.2
unnamed: C27.2, USB2.0 (SH), USB2.1 (SH), USB2.2 (SH), USB2.3 (SH)
unnamed: C40.1, C41.2
unnamed: C44.1, C45.2
unnamed: C55.1, C56.2
unnamed: C62.1, C63.2
unnamed: D1.2 (A), J4.2, Q1.3 (D)
unnamed: D2.2 (A), J5.2, Q2.3 (D)
unnamed: D3.2 (A), J6.2, Q3.3 (D)
unnamed: D4.2 (A), J7.2, Q4.3 (D)
unnamed: D6.6 (I/O1), R40.1
unnamed: D6.4 (I/O2), R39.2
unnamed: LED1.2 (DIN), R9.1
unnamed: LED1.4 (DOUT), LED2.2 (DIN)
unnamed: LED2.4 (DOUT), LED3.2 (DIN)
unnamed: LED3.4 (DOUT), LED4.2 (DIN)
unnamed: Q1.1 (G), R11.2, R12.2
unnamed: Q2.1 (G), R13.2, R20.2
unnamed: Q3.1 (G), R21.2, R22.2
unnamed: Q4.1 (G), R23.2, R24.2
unnamed: Q7.1 (G), R17.2, R28.1
unnamed: R3.2, SW3.1
unnamed: R8.2, SW2.3
unnamed: R17.1, SW1.2
unnamed: C4.2, R6.1, RP2350.46 (VREG_AVDD)
unnamed: L1.2, RP2350.48 (VREG_LX)
unnamed: R10.1, STATUS1.2 (DIN)
unnamed: R36.2, R37.1, U3.1 (FB)
unnamed: L5.1, U3.5 (SW)
unnamed: R19.2, U4.4 (B)
unnamed: C56.1, U6.3 (3V3)
unnamed: R32.2, U6.5 (IO2)
unnamed: R33.2, U6.22 (IO8)
unnamed: R41.1, USB2.A5 (CC1)
unnamed: R38.2, USB2.B5 (CC2)
unnamed: C7.2, R7.2, X1.3 (OSC2)
RP2350_GPIO_0: RP2350.2 (GPIO0), TP38.1 (1_1), U6.30 (RXD0)
RP2350_GPIO_1: RP2350.3 (GPIO1), TP40.1 (1_1), U6.31 (TXD0)
RP2350_GPIO_2: C52.2, R18.1, RP2350.4 (GPIO2), TP34.1 (1_1), U6.8 (EN)
RP2350_GPIO_3: RP2350.5 (GPIO3), TP36.1 (1_1), U6.23 (IO9)
RP2350_GPIO_4: RP2350.7 (GPIO4), U5.7 (INT)
RP2350_GPIO_5: R29.2, RP2350.8 (GPIO5), U1.4 (INT1)
RP2350_GPIO_6: RP2350.9 (GPIO6), U1.9 (INT2)
RP2350_GPIO_7: R31.2, RP2350.10 (GPIO7), U1.12 (CS)
RP2350_GPIO_8: RP2350.12 (GPIO8), U1.1 (SDO/SA0), U5.5 (SDO)
RP2350_GPIO_9: R30.2, RP2350.13 (GPIO9), U5.6 (CSB)
RP2350_GPIO_10: RP2350.14 (GPIO10), U1.13 (SCL), U5.2 (SCK)
RP2350_GPIO_11: RP2350.15 (GPIO11), U1.14 (SDA), U5.4 (SDI)
RP2350_GPIO_18: R12.1, RP2350.29 (GPIO18)
RP2350_GPIO_19: R13.1, RP2350.31 (GPIO19)
RP2350_GPIO_20: R21.1, RP2350.32 (GPIO20)
RP2350_GPIO_21: R23.1, RP2350.33 (GPIO21)
RP2350_GPIO_22: R27.1, RP2350.34 (GPIO22)
RP2350_GPIO_23: R10.2, RP2350.35 (GPIO23)
RP2350_GPIO_24: R14.2, R15.1, RP2350.36 (GPIO24)
RP2350_GPIO_25: RP2350.37 (GPIO25), U4.3 (A)
RP2350_GPIO_25_5.5V: R9.2, R19.1
RP2350_GPIO_26_ADC: C71.2, R25.2, R26.2, RP2350.40 (GPIO26/ADC0)
RP2350_QSPI_SCLK: FLASH1.6 (CLK), RP2350.56 (QSPI_SCLK)
RP2350_QSPI_SD0: FLASH1.5 (DI/IO_{0}), RP2350.57 (QSPI_SD0)
RP2350_QSPI_SD1: FLASH1.2 (DO/IO_{1}), RP2350.59 (QSPI_SD1)
RP2350_QSPI_SD2: FLASH1.3 (~WP/IO_{2}), RP2350.58 (QSPI_SD2)
RP2350_QSPI_SD3: FLASH1.7 (~HOLD/~RESET/IO_{3}), RP2350.55 (QSPI_SD3)
RP2350_QSPI_SS: FLASH1.1 (~CS), R3.1, RP2350.60 (~QSPI_SS)
RP2350_RUN: C9.1, RP2350.26 (RUN), SW2.1, TP35.1 (1_1)
RP2350_SWCLK: RP2350.24 (SWCLK), TP39.1 (1_1)
RP2350_SWDIO: RP2350.25 (SWDIO), TP37.1 (1_1)
RP2350_USB_DN: R40.2, RP2350.51 (USB_DM)
RP2350_USB_DP: R39.1, RP2350.52 (USB_DP)
RP2350_XIN: C8.1, RP2350.21 (XIN), X1.1 (OSC1)
RP2350_XOUT: R7.1, RP2350.22 (XOUT)
USB_D+: D6.3 (I/O2), USB2.A6 (DP1), USB2.B6 (DP2)
USB_D-: D6.1 (I/O1), USB2.A7 (DN1), USB2.B7 (DN2)
USB_VBUS: D6.5 (VBUS), R14.1, USB2.A4 (VBUS), USB2.A9 (VBUS), USB2.B4 (VBUS), USB2.B9 (VBUS)
UW_3.3V: C58.1, C59.1, C61.1, C69.1, L2.1, U2.5 (VDD), U2.6 (VCC), U2.7 (VCC)

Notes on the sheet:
GND
3.3V DECOUPLING
RP2350 DEBUG
IMU
LED ARRAY
BARO
VBUS
ESP32-C3 DEBUG
UWB ANCHOR
VBUS Divider
Motor 4
ESP32
3.3V-5V SIGNAL
Motor 1
USB-C Connector
BUZZ
1.1V DECOUPLING
STATUS LED
BATTERY
RP2350 CRYSTAL
MOTOR 1
ESD Protection
3.3V-5V BOOST
Motor 2
ARM
MOTOR 2
MOTOR 3
MOTOR 4
RP2350
FLASH RAM
V MON
3.7v
Motor 3
V MON
3.3V REG
Connectors will be solder pads
Dont flip flyback diode or else battery will go boom

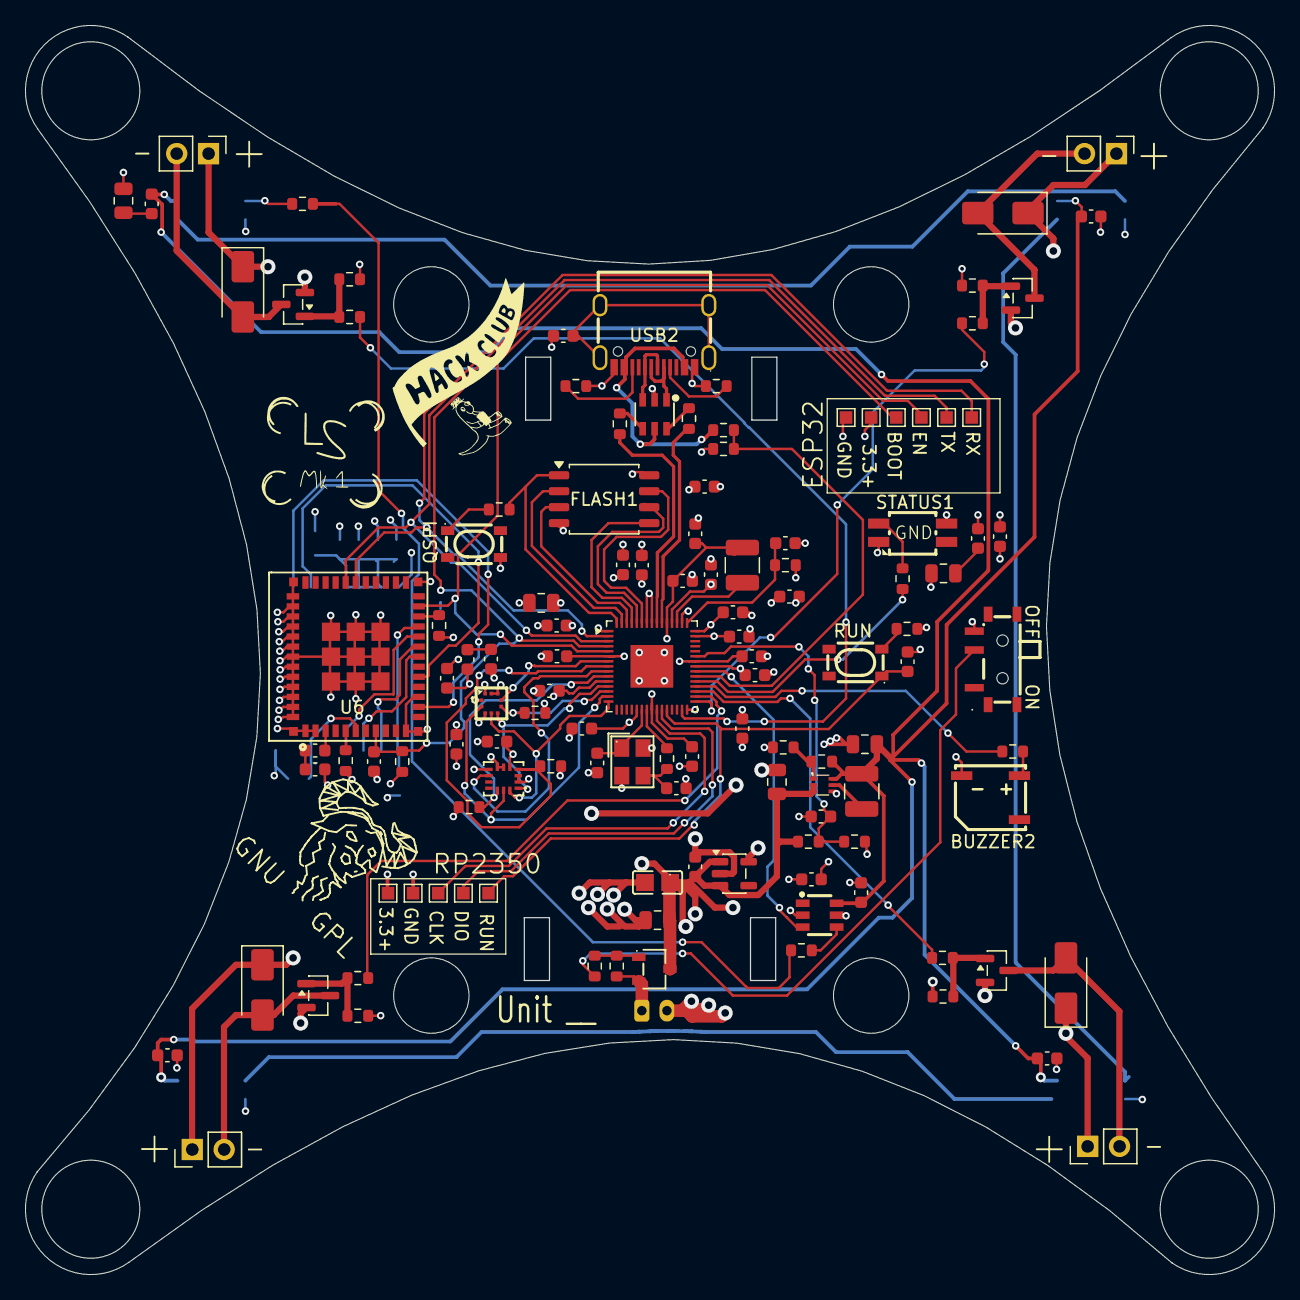
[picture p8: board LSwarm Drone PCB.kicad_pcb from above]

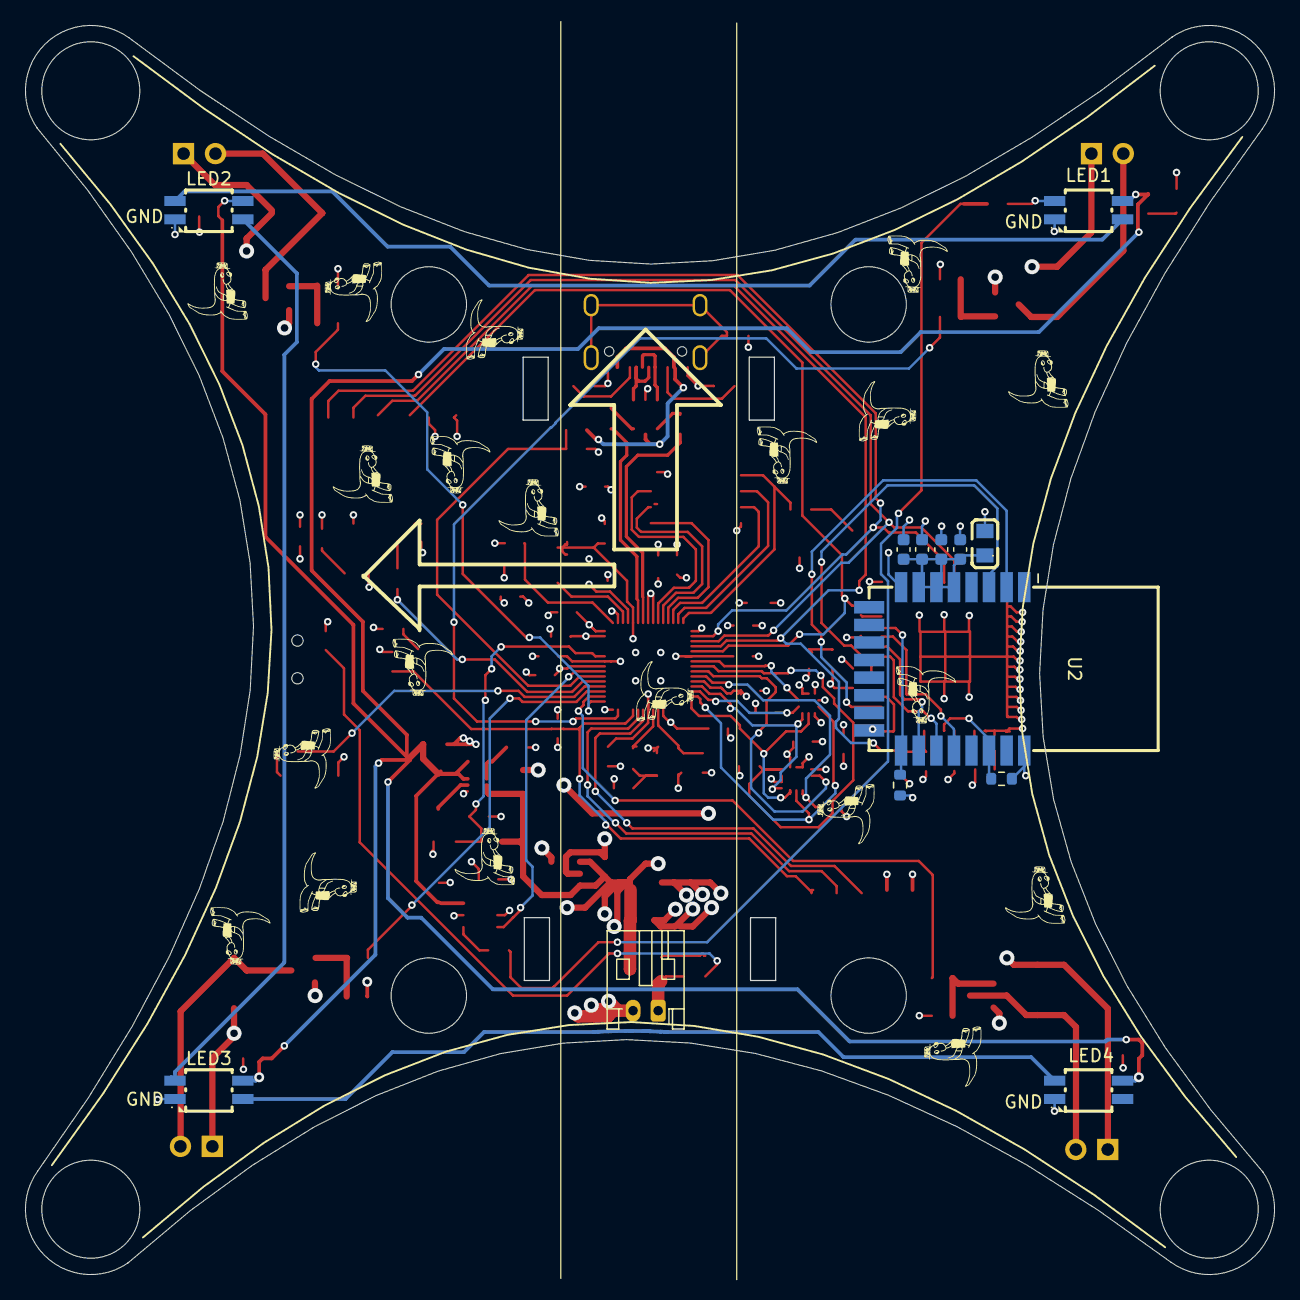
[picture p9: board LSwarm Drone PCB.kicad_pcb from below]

Board: 4 copper layers, 99.4 x 99.4 mm, 160 parts (33 on the bottom side), 88 nets.

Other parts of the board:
GNU: Symbol_GNU-Logo_SilkscreenTop
dino: LOGO; dino
dino#2, dino#3, dino#4, dino#5, dino#6, dino#7, dino#8, dino#9, dino#10, dino#11, dino#12, dino#13, dino#14, dino#15, dino#16, dino#17, dino#18, dino#19, dino#20, dino#21: LOGO; dino
hackclub: LOGO; hackclub
logo: LOGO; mk1Logo

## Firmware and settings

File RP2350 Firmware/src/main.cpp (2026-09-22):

#include <Arduino.h>
#include "pins.h"
#include "sensors.h"
#include "motors.h"
#include "hmi.h"
#include "esplink.h"
#include "selftest.h"

#if defined(ESP_PASSTHROUGH_ONLY)

void setup() {
  Serial.begin(115200);
  Motors::disarm();
  Hmi::begin();
  EspLink::begin();
  EspLink::passthrough();
}

void loop() {}

#else

static volatile bool g_armed = false;
static volatile float g_vbat = 0.0f;
static volatile bool g_sensorsOk = false;

static volatile uint16_t g_throttle[4] = {0, 0, 0, 0};

// Last position solution pushed up from the ESP32-S3 ("P,x,y,z,q").
static volatile float g_px = 0, g_py = 0, g_pz = 0; static volatile int g_pq = 0;

// Bench motor test: -1 = normal flight-control path, 0..3 = drive that one motor
// at g_motorTestPwm and hold the others off. Applied on core1 so all PWM writes
// stay on a single core (no cross-core race with analogWrite).
static volatile int8_t   g_motorTest    = -1;
static volatile uint16_t g_motorTestPwm = 0;

// When true, the periodic status-LED state machine is suspended so a manual
// 'status <r> <g> <b>' (or the self-test result colour) stays on screen.
static volatile bool     g_statusOverride = false;

static constexpr uint16_t MTEST_PWM = 220;   // ~22% - enough to spin a prop-less motor
static constexpr uint32_t MTEST_MS  = 700;   // per-motor spin duration

void setup() {
  Serial.begin(115200);

  Power::begin();
  Hmi::begin();
  Motors::disarm();
  EspLink::begin();

  Hmi::status(60, 30, 0);

  g_sensorsOk = Sensors::begin();

  uint32_t t0 = millis();
  while (!Serial && millis() - t0 < 2000) { 
    // wait for USB 
  }

  Serial.println("Init RP2350");
  Serial.printf("IMU  (LSM6DSR): %s\n", Sensors::imuOk()  ? "ok" : "FAIL");
  Serial.printf("BARO (BMP581) : %s\n", Sensors::baroOk() ? "ok" : "FAIL");
  Serial.printf("VBUS: %s   VBAT: %.2f V\n", Power::usbPresent() ? "present" : "absent", Power::batteryVolts());
  Serial.println("Type 'esp_bridge' to flash the ESP32-C3, 'help' for more.");

  Hmi::status(0, 40, 0);
  Hmi::beep(60);
}

static void handleCommand(const char* cmd) {
  if (!strcmp(cmd, "help")) {
        Serial.println("arm | disarm | t <0-3> <0-1000> | stat");
        Serial.println("selftest | mtest | m <0-3> <0-1000> | beep | status [<r> <g> <b>] | led <r> <g> <b>");
        Serial.println("esp_reset | esp_boot | esp_bridge");
  } else if (!strcmp(cmd, "arm")) {
      if (!g_sensorsOk) { Serial.println("refused: sensors failed"); return; }
      if (g_vbat < Power::VBAT_CRITICAL && !Power::usbPresent()) {
          Serial.println("refused: battery low"); return;
      }
      g_armed = true;
      Hmi::beep(120);
      Serial.println("ARMED");
  } else if (!strcmp(cmd, "disarm")) {
      g_armed = false;
      g_motorTest = -1;
      for (uint8_t i = 0; i < 4; i++) g_throttle[i] = 0;
      Serial.println("disarmed");
  } else if (!strcmp(cmd, "selftest")) {
      bool ok = SelfTest::run();
      g_statusOverride = true;                 // hold the result colour
      Hmi::status(ok ? 0 : 60, ok ? 60 : 0, 0);
      Serial.println("(status LED held; type 'status' to resume automatic)");
  } else if (!strcmp(cmd, "mtest")) {
      Serial.println("MOTOR TEST: remove propellers! spinning each motor ~0.7s in order...");
      for (uint8_t i = 0; i < 4; i++) {
          Serial.printf("  motor %u\n", i);
          g_motorTestPwm = MTEST_PWM;
          g_motorTest = (int8_t)i;
          delay(MTEST_MS);
          g_motorTest = -1;                    // core1 zeroes all outputs
          delay(400);
      }
      Serial.println("motor test complete");
  } else if (!strncmp(cmd, "m ", 2)) {
      int idx, val;
      if (sscanf(cmd + 2, "%d %d", &idx, &val) == 2 && idx >= 0 && idx < 4) {
          g_motorTestPwm = (uint16_t)constrain(val, 0, Motors::PWM_MAX);
          g_motorTest = (g_motorTestPwm == 0) ? -1 : (int8_t)idx;
          Serial.printf("bench motor %d = %d (props off!)\n", idx, g_motorTestPwm);
      } else {
          Serial.println("usage: m <0-3> <0-1000>");
      }
  } else if (!strcmp(cmd, "beep")) {
      Hmi::beep(120);
      Serial.println("beep");
  } else if (!strncmp(cmd, "status", 6)) {
      int r, g, b;
      if (sscanf(cmd + 6, "%d %d %d", &r, &g, &b) == 3) {
          g_statusOverride = true;
          Hmi::status(r, g, b);
          Serial.printf("status %d %d %d (override; 'status' alone resumes auto)\n", r, g, b);
      } else {
          g_statusOverride = false;
          Serial.println("status: automatic");
      }
  } else if (!strncmp(cmd, "led", 3)) {
      int r, g, b;
      if (sscanf(cmd + 3, "%d %d %d", &r, &g, &b) == 3) {
          Hmi::array(r, g, b);
          Serial.printf("led %d %d %d\n", r, g, b);
      } else {
          Serial.println("usage: led <r> <g> <b>");
      }
  } else if (!strncmp(cmd, "t ", 2)) {
      int idx, val;
      if (sscanf(cmd + 2, "%d %d", &idx, &val) == 2 && idx >= 0 && idx < 4) {
          g_throttle[idx] = (uint16_t)constrain(val, 0, Motors::PWM_MAX);
          Serial.printf("motor %d = %d\n", idx, g_throttle[idx]);
      }
  } else if (!strcmp(cmd, "stat")) {
      ImuSample imu; BaroSample baro;
      Sensors::readImu(imu); Sensors::readBaro(baro);
      Serial.printf("vbat %.2fV  usb %d  armed %d\n", g_vbat, Power::usbPresent(), g_armed);
      Serial.printf("acc %.2f %.2f %.2f g | gyro %.1f %.1f %.1f dps\n", imu.ax, imu.ay, imu.az, imu.gx, imu.gy, imu.gz);
      Serial.printf("baro %.1f Pa  %.1f C  alt %.1f m\n", baro.pressure_pa, baro.temperature_c, baro.altitude_m);
  } else if (!strcmp(cmd, "esp_reset")) {
      EspLink::reset();  Serial.println("ESP32 reset");
  } else if (!strcmp(cmd, "esp_boot")) {
      EspLink::enterBootloader(); Serial.println("ESP32 in bootloader");
  } else if (!strcmp(cmd, "esp_bridge")) {
      g_armed = false;
      Motors::disarm();
      Serial.println("entering programmer mode - reset RP2350 to exit");
      Serial.flush();
      EspLink::passthrough();
  }
}

// Lines coming up from the ESP32-S3 over Serial1.
//   S,<text>       -> log to USB console
//   P,x,y,z,q      -> position solution (store for flight/telemetry)
//   N,id,x,y,z     -> neighbour position (ESP-NOW relay)  [ignored for now]
//   C,<cmd>...     -> command from the Pi, mapped onto the local console verbs
static void handleEspLine(char* s) {
  if (s[0] == 'P') {
    float x, y, z; int q;
    if (sscanf(s + 2, "%f,%f,%f,%d", &x, &y, &z, &q) == 4) {
      g_px = x; g_py = y; g_pz = z; g_pq = q;
    }
  } else if (s[0] == 'C') {
    // Translate "C,verb,a,b,c" into the existing console command "verb a b c".
    char cmd[48]; size_t j = 0;
    for (char* p = s + 2; *p && j < sizeof(cmd) - 1; p++)
      cmd[j++] = (*p == ',') ? ' ' : *p;
    cmd[j] = 0;
    handleCommand(cmd);
  } else {
    Serial.println(s);            // S,... and anything else -> console
  }
}

void loop() {
  static char line[48];
  static uint8_t n = 0;
  while (Serial.available()) {
    char c = (char)Serial.read();
    if (c == '\n' || c == '\r') {
        if (n) {
          line[n] = 0; handleCommand(line); n = 0;
        }
      } else if (n < sizeof(line) - 1) {
        line[n++] = c;
      }
  }

  static char eline[96];
  static uint8_t en = 0;
  while (Serial1.available()) {
      char c = (char)Serial1.read();
      if (c == '\n' || c == '\r') {
          if (en) { eline[en] = 0; handleEspLine(eline); en = 0; }
      } else if (en < sizeof(eline) - 1) {
          eline[en++] = c;
      }
  }

  static uint32_t tLast = 0;
  if (millis() - tLast >= 200) {
    tLast = millis();
    g_vbat = Power::batteryVolts();

    // Push telemetry up to the ESP32-S3 -> Pi ("T,vbat,armed,usb").
    Serial1.printf("T,%.2f,%d,%d\n", g_vbat, g_armed ? 1 : 0, Power::usbPresent() ? 1 : 0);

    if (!g_statusOverride) {
        if (!g_sensorsOk) Hmi::status(60, 0, 0);
        else if (g_vbat < Power::VBAT_CRITICAL) Hmi::status(60, 0, 0);
        else if (g_vbat < Power::VBAT_WARN) Hmi::status(60, 30, 0);
        else if (g_armed) Hmi::status(0, 60, 0);
        else Hmi::status(0, 0, 30);
    }

    if (g_armed && g_vbat < Power::VBAT_CRITICAL && !Power::usbPresent()) {
        g_armed = false;
        for (uint8_t i = 0; i < 4; i++) g_throttle[i] = 0;
        Hmi::beep(300);
    }
  }
}

void setup1() {
  Motors::begin();
}

void loop1() {
  static uint32_t next = 0;
  uint32_t now = micros();
  if ((int32_t)(now - next) < 0) return;

  next = now + 1000; // 1 kHz

  // Bench motor test overrides the flight-control path ('mtest' / 'm' commands).
  if (g_motorTest >= 0) {
      for (uint8_t i = 0; i < 4; i++)
          Motors::set(i, (i == g_motorTest) ? g_motorTestPwm : 0);
      return;
  }

  ImuSample imu;
  if (!Sensors::readImu(imu)) { Motors::disarm(); return; }

  if (g_armed) {
      for (uint8_t i = 0; i < 4; i++) Motors::set(i, g_throttle[i]);
  } else {
      Motors::setAll(0);
  }
}

#endif 

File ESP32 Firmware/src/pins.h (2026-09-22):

#pragma once
#include <cstdint>

// ---------------------------------------------------------------------------
// External ESP32-S3 Super Mini pin map (drone).
//
// The on-board ESP32-C3-MINI (U8) is bypassed. An external ESP32-S3 Super Mini
// is wired to the 6-pin "ESP32" header (GND 3V3 BOOT EN TX RX) for the RP2350
// link, and (optionally) to a DW3000 UWB add-on module for anchor ranging.
//
// Pick only "safe" S3 GPIOs. Avoid 0/3/45/46 (strapping), 19/20 (USB), 43/44
// (USB-serial-jtag TX/RX) and 48 (on-board RGB LED).
// ---------------------------------------------------------------------------

// UART link to the RP2350 (Serial1). Cross-wired at the header:
//   header TX (RP2350 GPIO0, RP2350 out) -> S3 RX below
//   header RX (RP2350 GPIO1, RP2350 in)  <- S3 TX below
static constexpr int PIN_LINK_RX = 4;
static constexpr int PIN_LINK_TX = 5;
static constexpr uint32_t LINK_BAUD = 115200;

// On-board DW3000 UWB tag (SPI). The tag is on the drone PCB; its DW nets route
// to the dead ESP32-C3 pads. Tap them there and run to these S3 GPIOs. The C3
// pin each DW net lands on (find the pad):
//   WAKEUP=C3 IO1  IRQ=C3 IO3  MISO=C3 IO4  MOSI=C3 IO5
//   CLK=C3 IO6     CS=C3 IO7   RST=C3 IO10
static constexpr int PIN_DW_MOSI   = 11;
static constexpr int PIN_DW_SCK    = 12;
static constexpr int PIN_DW_MISO   = 13;
static constexpr int PIN_DW_CS     = 10;
static constexpr int PIN_DW_IRQ    = 9;
static constexpr int PIN_DW_RST    = 8;
static constexpr int PIN_DW_WAKEUP = 7;

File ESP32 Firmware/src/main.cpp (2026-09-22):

#include <Arduino.h>
#include <WiFi.h>
#include <WiFiUdp.h>
#include <esp_now.h>
#include <esp_wifi.h>
#include "pins.h"
#include "uwb.h"

// ===========================================================================
// LSwarm drone radio brain (external ESP32-S3 Super Mini)
//
//   RP2350 (flight controller)  <--UART-->  this ESP32-S3
//   this ESP32-S3               <--WiFi-->  Raspberry Pi Zero 2 W (AP)
//   this ESP32-S3               <-ESP-NOW-> peer drones
//   this ESP32-S3 + DW3000      <--UWB--->  LS Anchors  (ranging -> position)
//
// Position is solved on the Pi: the drone sends anchor ranges up, the Pi
// trilaterates and sends "P,x,y,z,q" back. That keeps this firmware small and
// the math testable in Python. See SETUP_EXTERNAL_ESP32.txt.
// ===========================================================================

// ---- per-drone / site config (EDIT THESE) --------------------------------
static constexpr uint8_t  DRONE_ID   = 1;
static const char*        WIFI_SSID  = "LSwarm";
static const char*        WIFI_PASS  = "swarmnet";
static const char*        PI_IP      = "192.168.4.1";
static constexpr uint16_t PI_PORT    = 9000;   // Pi listens here
static constexpr uint16_t LOCAL_PORT = 9001;   // we listen here for replies

// Anchor UWB addresses to range against. Must match the anchors' `id`.
static const uint8_t ANCHORS[] = {1, 2, 3, 4};
static constexpr size_t N_ANCHORS = sizeof(ANCHORS);

// Broadcast MAC for ESP-NOW neighbour sharing.
static uint8_t BCAST[6] = {0xFF,0xFF,0xFF,0xFF,0xFF,0xFF};
// --------------------------------------------------------------------------

static WiFiUDP udp;
static float g_x=0, g_y=0, g_z=0; static int g_q=0;   // last known position
static float g_vbat=0; static int g_armed=0;          // from RP2350 telemetry

static void toRp(const char* s) { Serial1.println(s); }

// ---- ESP-NOW: share our position, hear neighbours ------------------------
static void onEspNowRecv(const esp_now_recv_info_t*, const uint8_t* data, int len) {
    // "N,<id>,<x>,<y>,<z>" from a peer -> hand to RP2350 as a neighbour hint.
    if (len < 2 || data[0] != 'N') return;
    char buf[64]; int n = len < 63 ? len : 63;
    memcpy(buf, data, n); buf[n] = 0;
    Serial1.println(buf);            // RP2350 may use this for spacing
}

static void espNowShare() {
    char msg[64];
    int n = snprintf(msg, sizeof(msg), "N,%u,%.2f,%.2f,%.2f", DRONE_ID, g_x, g_y, g_z);
    esp_now_send(BCAST, (uint8_t*)msg, n);
}

// ---- WiFi + UDP ----------------------------------------------------------
static void wifiConnect() {
    WiFi.mode(WIFI_STA);
    WiFi.begin(WIFI_SSID, WIFI_PASS);
    uint32_t t0 = millis();
    while (WiFi.status() != WL_CONNECTED && millis() - t0 < 8000) delay(100);
    udp.begin(LOCAL_PORT);
}

static void handlePiPacket(char* p) {
    // "P,x,y,z,q"  -> position solution   |  "C,..." -> command for RP2350
    if (p[0] == 'P') {
        sscanf(p + 2, "%f,%f,%f,%d", &g_x, &g_y, &g_z, &g_q);
        Serial1.println(p);                  // forward position to flight ctrl
        espNowShare();
    } else if (p[0] == 'C') {
        Serial1.println(p);                  // forward command verbatim
    }
}

static void pumpUdp() {
    int sz = udp.parsePacket();
    if (sz <= 0) return;
    char buf[128];
    int n = udp.read(buf, sizeof(buf) - 1);
    if (n <= 0) return;
    buf[n] = 0;
    handlePiPacket(buf);
}

// ---- RP2350 link: read its telemetry lines -------------------------------
static void pumpRp() {
    static char line[96]; static uint8_t n = 0;
    while (Serial1.available()) {
        char c = (char)Serial1.read();
        if (c == '\n' || c == '\r') {
            if (n) {
                line[n] = 0;
                if (line[0] == 'T')          // "T,vbat,armed,usb"
                    sscanf(line + 2, "%f,%d", &g_vbat, &g_armed);
                n = 0;
            }
        } else if (n < sizeof(line) - 1) line[n++] = c;
    }
}

// ---- UWB ranging round ---------------------------------------------------
static void rangeAndReport() {
    char msg[160];
    int off = snprintf(msg, sizeof(msg), "R,%u", DRONE_ID);
    bool any = false;
    for (size_t i = 0; i < N_ANCHORS; i++) {
        float d;
        if (Uwb::rangeTo(ANCHORS[i], d)) {
            off += snprintf(msg + off, sizeof(msg) - off, ",%u,%.3f", ANCHORS[i], d);
            any = true;
        }
    }
    if (any && WiFi.status() == WL_CONNECTED) {
        udp.beginPacket(PI_IP, PI_PORT);
        udp.write((uint8_t*)msg, off);
        udp.endPacket();
    }
}

static void reportHealth() {
    if (WiFi.status() != WL_CONNECTED) return;
    char msg[64];
    int n = snprintf(msg, sizeof(msg), "D,%u,%.2f,%d,%d",
                     DRONE_ID, g_vbat, g_armed, Uwb::ok() ? 1 : 0);
    udp.beginPacket(PI_IP, PI_PORT);
    udp.write((uint8_t*)msg, n);
    udp.endPacket();
}

void setup() {
    Serial.begin(115200);                                   // USB debug
    Serial1.begin(LINK_BAUD, SERIAL_8N1, PIN_LINK_RX, PIN_LINK_TX);
    delay(50);
    toRp("S,esp32-s3 boot");

    wifiConnect();

    // ESP-NOW must share the AP's channel to coexist with WiFi-STA.
    esp_wifi_set_channel(WiFi.channel(), WIFI_SECOND_CHAN_NONE);
    if (esp_now_init() == ESP_OK) {
        esp_now_register_recv_cb(onEspNowRecv);
        esp_now_peer_info_t peer = {};
        memcpy(peer.peer_addr, BCAST, 6);
        peer.channel = WiFi.channel();
        esp_now_add_peer(&peer);
    }

    if (Uwb::begin()) toRp("S,UWB ready");
    else              toRp("S,UWB NOT DETECTED (ranging off)");

    toRp(WiFi.status() == WL_CONNECTED ? "S,wifi ok" : "S,wifi DOWN");
}

void loop() {
    pumpRp();
    pumpUdp();

    static uint32_t tRange = 0;
    if (millis() - tRange >= 100) { tRange = millis(); rangeAndReport(); }   // 10 Hz

    static uint32_t tHealth = 0;
    if (millis() - tHealth >= 1000) { tHealth = millis(); reportHealth(); }

    if (WiFi.status() != WL_CONNECTED) {
        static uint32_t tRetry = 0;
        if (millis() - tRetry >= 3000) { tRetry = millis(); WiFi.reconnect(); }
    }
}

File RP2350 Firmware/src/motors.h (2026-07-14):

#pragma once
#include <Arduino.h>
#include "pins.h"

namespace Motors {

static constexpr uint16_t PWM_MAX  = 1000; 
static constexpr uint32_t PWM_FREQ = 24000;

inline void begin() {
    analogWriteFreq(PWM_FREQ);
    analogWriteRange(PWM_MAX);
    for (uint8_t i = 0; i < 4; i++) {
        pinMode(PIN_MOTOR[i], OUTPUT);
        digitalWrite(PIN_MOTOR[i], LOW);
    }
}

inline void set(uint8_t idx, uint16_t throttle) {
    if (idx > 3) return;
    if (throttle > PWM_MAX) throttle = PWM_MAX;
    analogWrite(PIN_MOTOR[idx], throttle);
}

inline void setAll(uint16_t t) { for (uint8_t i = 0; i < 4; i++) set(i, t); }

inline void disarm() {
    for (uint8_t i = 0; i < 4; i++) {
        analogWrite(PIN_MOTOR[i], 0);
        pinMode(PIN_MOTOR[i], OUTPUT);
        digitalWrite(PIN_MOTOR[i], LOW);
    }
}

} 

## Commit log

2026-04-25 finished the schematic!!!!
    [LSwarm Drone PCB.kicad_sch]
2026-04-25 imported components correctly into the pcb wiring design
    [LSwarm Drone PCB.kicad_pcb, LSwarm Drone PCB.kicad_sch]
2026-04-28 finished pcb layout
    [LSwarm Drone PCB.kicad_pcb, LSwarm Drone PCB.kicad_sch]
2026-04-28 finished main wiring
    [LSwarm Drone PCB.kicad_pcb]
2026-04-29 added graphics + other stuff
    [LSwarm Drone PCB.kicad_pcb]
2026-06-10 finished new pcb wiring
    [LSwarm Drone PCB.kicad_pcb, LSwarm Drone PCB.kicad_sch]
2026-06-20 added vbus connection to rp2350
    [LSwarm Drone PCB.kicad_pcb, LSwarm Drone PCB.kicad_sch]
